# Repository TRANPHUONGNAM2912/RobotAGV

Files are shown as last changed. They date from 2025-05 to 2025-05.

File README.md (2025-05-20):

# RobotAGV

Một triển khai mô-đun và hướng đối tượng của robot AGV (Automated Guided Vehicle) sử dụng ESP32.

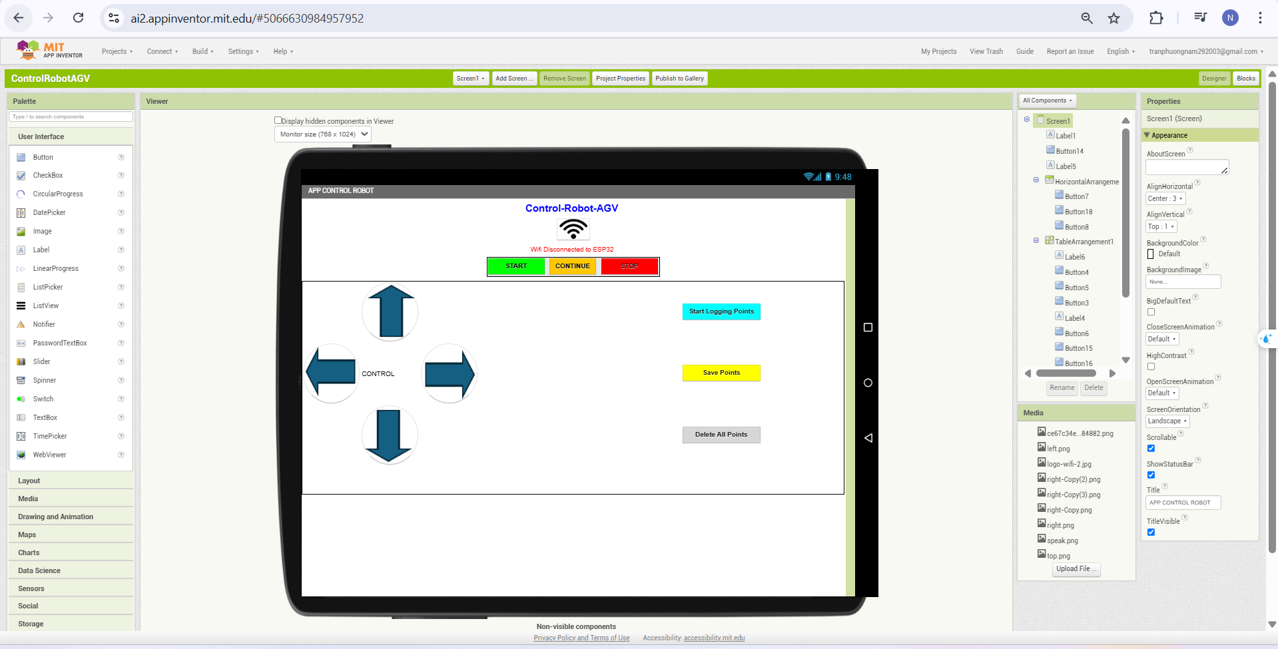
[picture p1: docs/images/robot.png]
RobotAGV


## Tổng Quan Dự Án

Repository này chứa toàn bộ mã nguồn của robot AGV dựa trên nền tảng ESP32. Dự án được cấu trúc theo nguyên tắc lập trình hướng đối tượng để dễ bảo trì và mở rộng.

### Tính Năng Chính

- **Điều hướng theo phương pháp dạy và thực hiện**: Dạy robot các đường đi thông qua ứng dụng di động mà không cần dùng dò line
- **Điều khiển PID-Backstepping**: Thuật toán điều khiển tiên tiến cho việc bám quỹ đạo chính xác
- **Điều khiển từ xa qua WiFi**: Điều khiển robot thông qua ứng dụng di động hoặc giao diện web
- **Theo dõi vị trí**: Đo lường chính xác vị trí sử dụng bộ mã hóa bánh xe
- **Kiến trúc mô-đun**: Cấu trúc mã nguồn hướng đối tượng được tổ chức tốt

## Cấu Trúc Dự Án

Mã nguồn được tổ chức thành nhiều mô-đun:

- **RobotAGV.ino**: File sketch Arduino chính khởi tạo và điều phối tất cả các thành phần
- **Config.h**: File cấu hình trung tâm với tất cả các tham số và định nghĩa chân
- **Motor.h**: Lớp điều khiển động cơ với chức năng PWM
- **Encoder.h/Encoder.cpp**: Quản lý bộ mã hóa và xử lý ngắt
- **PIDController.h**: Triển khai thuật toán điều khiển PID
- **Robot.h**: Lớp robot chính xử lý động học, theo dõi vị trí và bám quỹ đạo
- **WebServer.h**: Giao diện web để điều khiển từ xa qua WiFi

## Chi Tiết Kỹ Thuật

### Động Học Robot
- Robot sử dụng động học vi sai (differential drive)
- Theo dõi vị trí sử dụng bộ mã hóa bánh xe (x, y, theta)
- Bám quỹ đạo với hiệu chỉnh lỗi trong hệ tọa độ của robot

### Hệ Thống Điều Khiển
- Bộ điều khiển PID cho mỗi động cơ
- Thuật toán bám quỹ đạo với giảm thiểu lỗi vị trí và hướng
- Triển khai chống tích lũy (anti-windup) cho điều khiển tích phân

### Truyền Thông
- Điểm truy cập WiFi để kết nối trực tiếp
- API HTTP đơn giản cho các lệnh điều khiển
- Giao diện ứng dụng di động để dạy quỹ đạo

## Yêu Cầu Phần Cứng

- Board phát triển ESP32
- Hai động cơ DC với bộ mã hóa (234.3 xung/vòng)
- Driver động cơ H-bridge
- Màn hình LCD I2C (16x2)
- Nút nhấn để điều khiển vật lý
- Nguồn điện

## Thiết Kế PCB

Thư mục `pcb` chứa các file thiết kế PCB Altium cho phần cứng điện tử của robot. PCB tích hợp:
- Vi điều khiển ESP32
- Mạch điều khiển động cơ
- Giao diện bộ mã hóa
- Quản lý nguồn điện
- Kết nối I/O

## Ứng Dụng Di Động

Thư mục `app` chứa ứng dụng di động được thiết kế với MIT App Inventor cho phép:
- Dạy robot các đường đi mới
- Điều khiển từ xa chuyển động của robot
- Lưu trữ và quản lý nhiều quỹ đạo
- Giám sát trạng thái robot

## Hướng Dẫn Sử Dụng

### Thiết Lập
1. Tải mã nguồn lên board ESP32 với các kết nối phần cứng cần thiết
2. Bật nguồn robot
3. Kết nối với điểm truy cập WiFi (SSID: ESP32-AP, Mật khẩu: 123456789)

### Điều Khiển Từ Xa
Điều khiển robot bằng cách gửi yêu cầu HTTP đến:
- `/T`: Di chuyển tiến
- `/B`: Di chuyển lùi
- `/L`: Rẽ trái
- `/R`: Rẽ phải
- `/0`: Dừng lại
- `/1`: Bắt đầu bám quỹ đạo
- `/2`: Dừng bám quỹ đạo
- `/3`: Bắt đầu ghi quỹ đạo
- `/4`: Dừng ghi quỹ đạo
- `/5`: Xóa quỹ đạo đã ghi
- `/6`: Tiếp tục bám quỹ đạo

### Điều Khiển Vật Lý
- **Nút Start**: Bắt đầu bám quỹ đạo
- **Nút Stop**: Dừng khẩn cấp

## Chi Tiết Triển Khai

### Hệ Tọa Độ
- X: Vị trí tiến/lùi tính bằng mét
- Y: Vị trí trái/phải tính bằng mét
- Theta: Hướng tính bằng radian

### Bám Quỹ Đạo
Robot có thể ghi lại quỹ đạo khi bạn điều khiển thủ công, sau đó thực hiện lại quỹ đạo đó bằng thuật toán điều khiển giảm thiểu lỗi vị trí và hướng.

### Tính Năng Chính
1. **Dạy qua Ứng dụng Di động**: Robot có thể được dạy các đường đi thông qua ứng dụng di động mà không cần dùng đường dò line dán dưới sàn.
2. **Thuật toán PID-Backstepping**: Sử dụng điều khiển tiên tiến để bám quỹ đạo chính xác.
3. **Tự động Hiệu chỉnh Đường đi**: Nếu bị đẩy ra khỏi quỹ đạo, robot tự động quay lại đúng đường đã lập trình.
4. **Lưu trữ Vị trí**: Lưu dữ liệu vị trí để hoạt động nhất quán.
5. **Phát hiện Vật cản**: Tự động dừng lại khi phát hiện vật cản.

## Cài Đặt

1. Clone repository này
2. Mở file `src/RobotAGV.ino` trong Arduino IDE
3. Cài đặt các thư viện cần thiết:
   - WiFi
   - WebServer
   - MatrixMath
   - Wire
   - LiquidCrystal_I2C
4. Kết nối board ESP32
5. Tải sketch lên board

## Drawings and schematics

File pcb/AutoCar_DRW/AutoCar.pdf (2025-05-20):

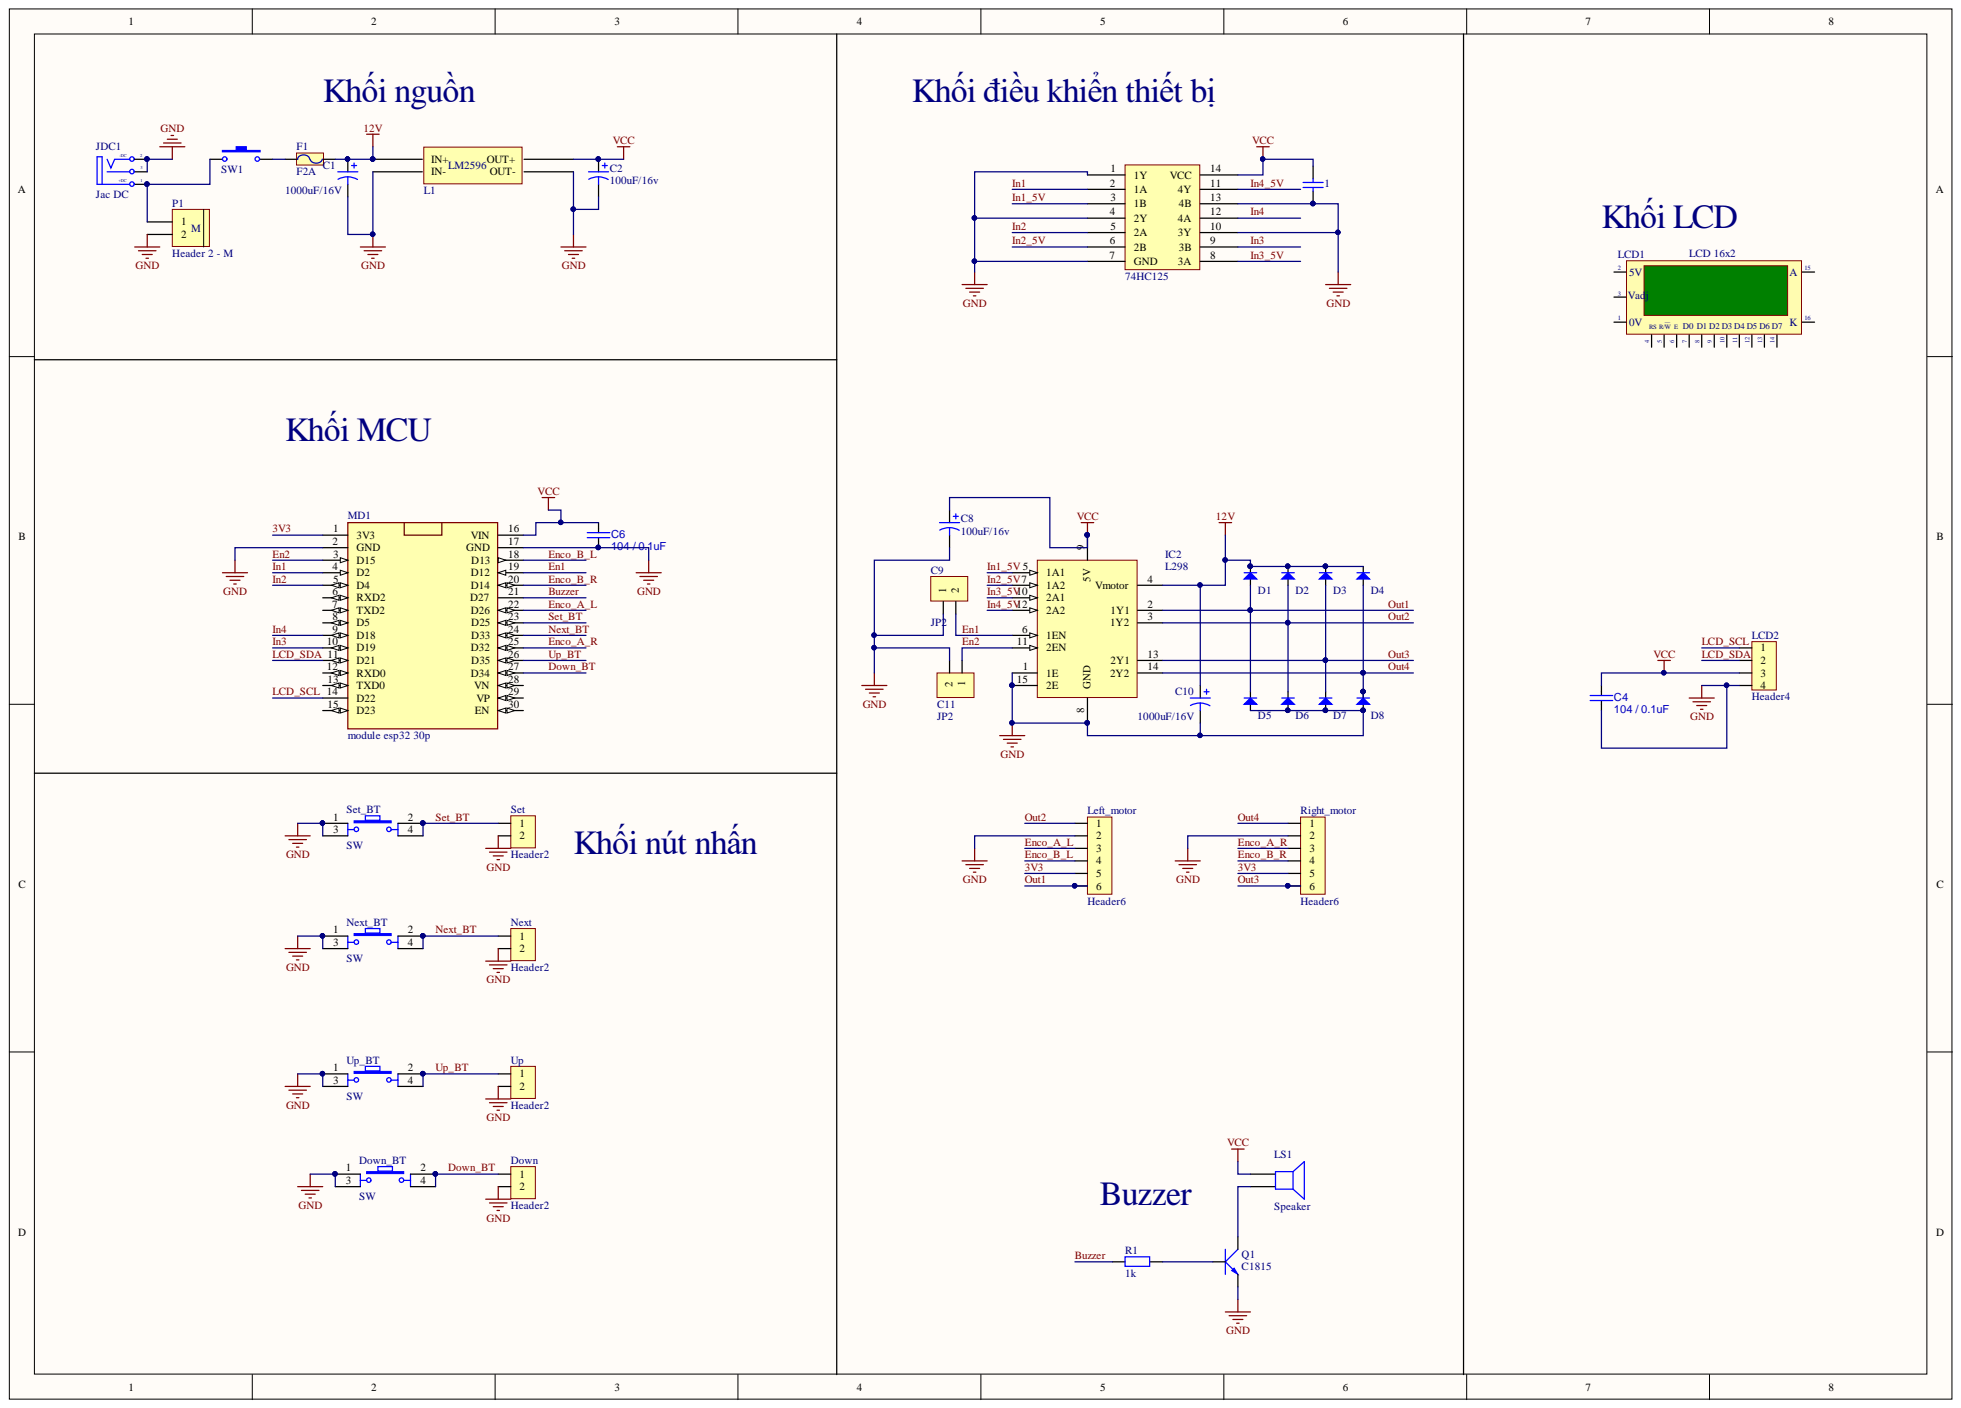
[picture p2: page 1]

Khối điều khiển thiết bị

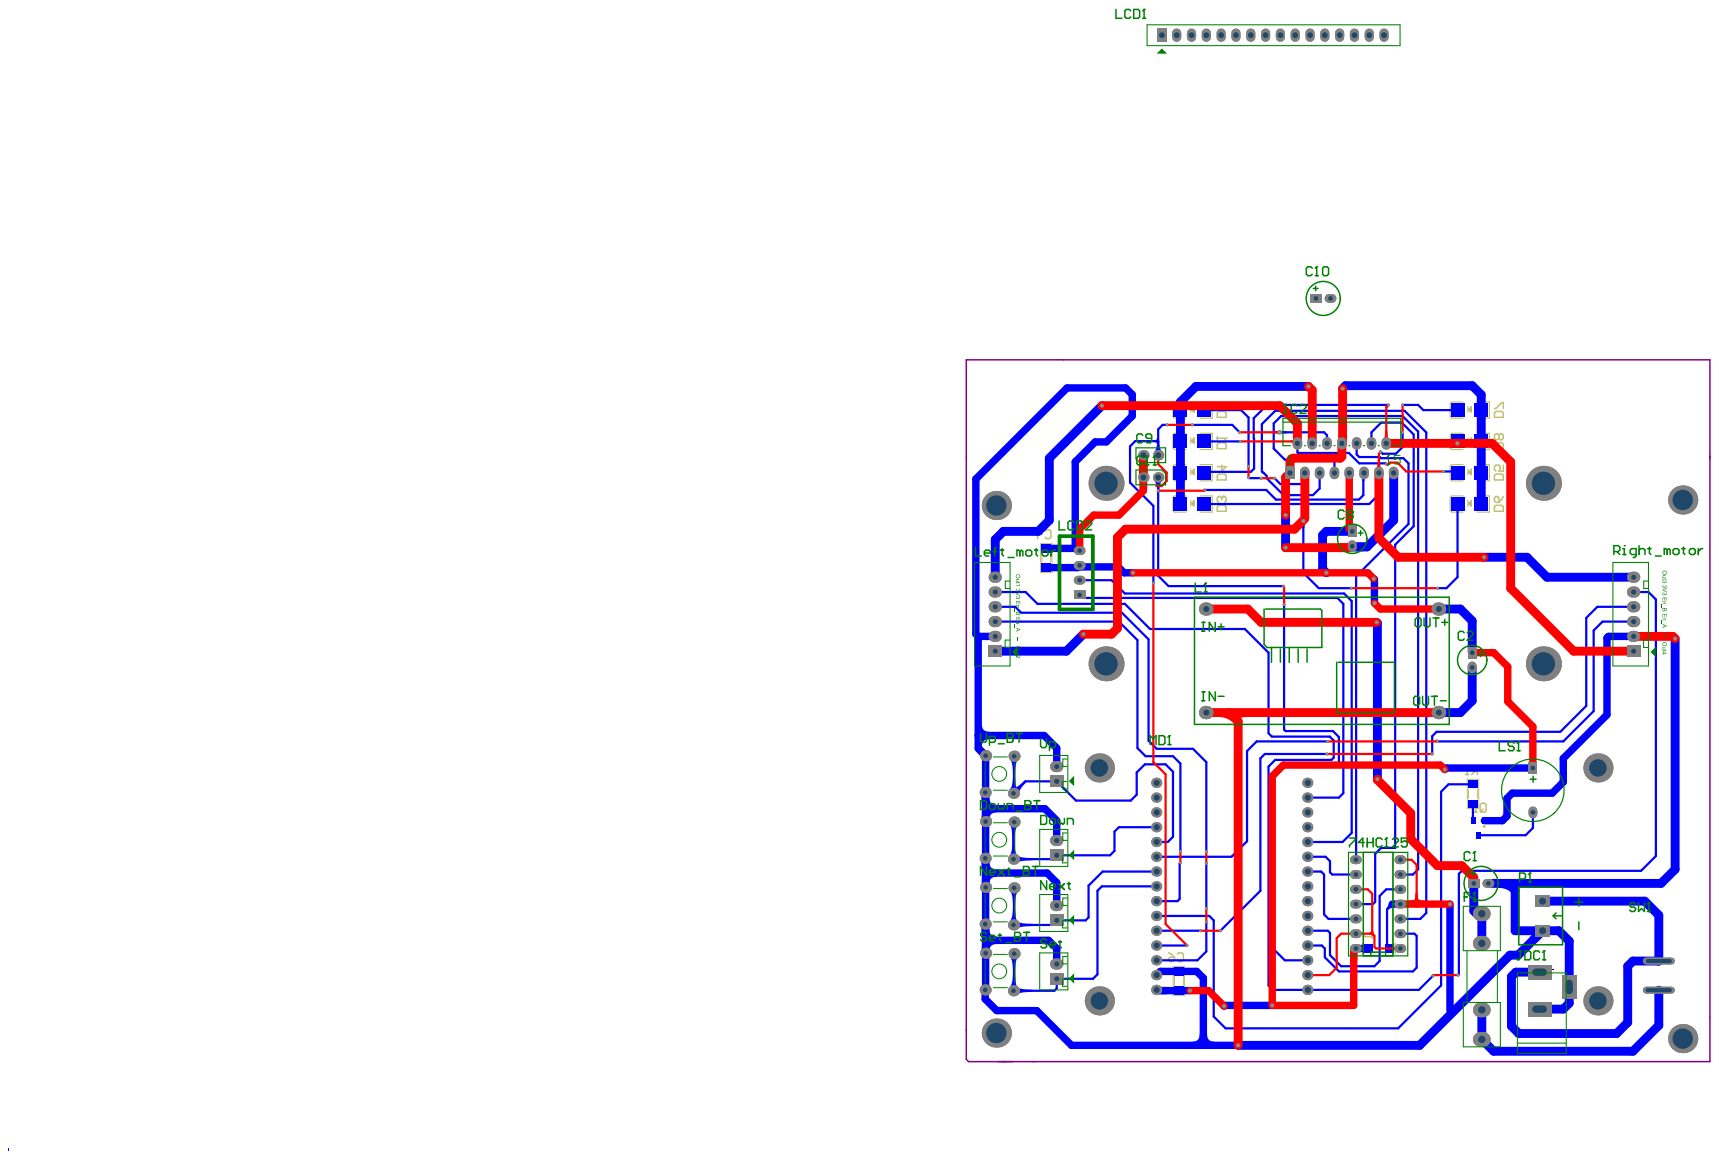
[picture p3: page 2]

Comment | Description | Designator | Footprint | LibRef | Quantity
Capacitor Ceramic | Capacitor | 1 | C1206 | CapSMD | 1
74HC02 DIP14 | Cắm | 74HC125 | dip14 | 74HC02 DIP | 1
1000uF/16V | Polarized Capacitor (Axial) | C1, C10 | C8mm | Cap Pol 12mm | 2
100uF/16v | Polarized Capacitor (Axial) | C2, C8 | C5mm | Cap Pol 5mm | 2
approved sub OK | Capacitor SMD Cer 1.8nF 10% 50V X7R 0805 | C4, C6 | SMD Capacistor 1206 | CAP C_0805 | 2
JP2 | WR-PHD 2.54 mm Angled Socket Header | C9, C11 | JP2-CLOSED | JP2 | 2
Diode SMD | Default Diode | D1, D2, D3, D4, D5, D6, D7, D8 | DIO-SMD-106 | Diode SMD | 8
Header2 | Header IDC, 2 x 1 Pin Vertical 2.54mm Pitch (Non-Boxed, Male) | Down, Next, Set, Up | Header2 | Header2 | 4
SW | Switch button 4 pin | Down_BT, Next_BT, Set_BT, Up_BT | SW4 | SW4 | 4
F2A | Fuse | F1 | Fuse | Fuse | 1
L298 | Dual Full-H Driver | IC2 | DIP15SL2 | L298 | 1
Jac DC | Jac DC input | JDC1 | DC-IN | DCIN | 1
BUCK_LM2596 | | L1 | BUCK_LM2596 | BUCK_LM2596 | 1
LCD 16x2 | | LCD1 | LCD16X2N | LCD | 1
Header4 | Header IDC, 4 x 1 Pin Vertical 2.54mm Pitch (Non-Boxed, Male) | LCD2 | XH2.54M-4 | Header4 | 1
Header6 | Header IDC, 6 x 1 Pin Vertical 2.54mm Pitch (Non-Boxed, Male) | Left_motor, Right_motor | Header6 | Header6 | 2
Speaker | Loudspeaker | LS1 | SPEAKER | Speaker | 1
module esp32 30p | | MD1 | module esp32 30 pin | module esp32 30p | 1
Header 2 - M | Header, 2-Pin, Medium | P1 | Medium - Header 2 | Header 2 - M | 1
C1815 | NPN 600mW, ECB | Q1 | SOT23B | C1815 | 1
1k | Resistor SMD 0805 | R1 | RES-SMD-1206 | R0805 | 1
KCD01-11_SWITCH | Nut Nhan 2 Chan SMD 3x6x2. SW1 | | KCD01-11 | KCD01-11_SWITCH | 1

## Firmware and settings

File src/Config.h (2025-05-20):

#ifndef CONFIG_H
#define CONFIG_H

// WiFi configuration
#define WIFI_SSID "ESP32-AP"
#define WIFI_PASSWORD "123456789"

// Robot physical parameters
#define WHEEL_DISTANCE 0.18 // Distance between wheels in meters
#define WHEEL_RADIUS 0.0325 // Wheel radius in meters (0.065/2)
#define ENCODER_TICKS_PER_REV 234.3 // Encoder ticks per revolution

// PID Controller parameters
#define PID_KP 0.02
#define PID_KI 0.00015
#define PID_KD 0.01
#define PID_MAX_OUTPUT 12.0
#define PID_MIN_OUTPUT 0.0

// Motor pins
#define MOTOR1_PIN1 2
#define MOTOR1_PIN2 4
#define MOTOR1_ENABLE 12
#define MOTOR2_PIN1 19
#define MOTOR2_PIN2 18
#define MOTOR2_ENABLE 15

// Encoder pins
#define ENCODER1_A 26
#define ENCODER1_B 13
#define ENCODER2_A 32
#define ENCODER2_B 14

// Button pins
#define BUTTON_START 25
#define BUTTON_STOP 33

// PWM configuration
#define PWM_FREQUENCY 30000
#define PWM_RESOLUTION 8
#define PWM_CHANNEL_1 0
#define PWM_CHANNEL_2 1

// LCD configuration
#define LCD_ADDRESS 0x27
#define LCD_COLUMNS 16
#define LCD_ROWS 2

// Timer configuration
#define TIMER_INTERVAL_US 150000 // 150ms

// Trajectory parameters
#define MAX_TRAJECTORY_POINTS 1000
#define DEFAULT_LINEAR_VELOCITY 0.15
#define DEFAULT_ANGULAR_VELOCITY 0.4

// Web server port
#define SERVER_PORT 80

#endif // CONFIG_H 

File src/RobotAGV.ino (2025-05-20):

#include "Config.h"
#include "Motor.h"
#include "Encoder.h"
#include "PIDController.h"
#include "Robot.h"
#include "WebServer.h"
#include <Wire.h>

// Global objects
Robot* robot = nullptr;
WebServerController* webServer = nullptr;

// Timer interrupt
hw_timer_t* timer = nullptr;
volatile unsigned long timerCount = 0;

void IRAM_ATTR onTimer() {
    timerCount++;
}

// Button interrupt handler
void IRAM_ATTR stopButtonHandler() {
    if (robot) {
        robot->stop();
    }
}

void setup() {
    // Initialize serial communication
    Serial.begin(115200);
    Serial.println("Initializing RobotAGV...");
    
    // Initialize I2C for LCD
    Wire.begin();
    
    // Create robot instance
    robot = new Robot();
    
    // Create web server instance
    webServer = new WebServerController(robot);
    
    // Initialize encoders
    encoder1 = new Encoder(ENCODER1_A, ENCODER1_B);
    encoder2 = new Encoder(ENCODER2_A, ENCODER2_B);
    
    // Set up button interrupts
    pinMode(BUTTON_START, INPUT_PULLUP);
    pinMode(BUTTON_STOP, INPUT_PULLUP);
    attachInterrupt(digitalPinToInterrupt(BUTTON_STOP), stopButtonHandler, FALLING);
    
    // Set up encoder interrupts
    attachInterrupt(digitalPinToInterrupt(ENCODER1_A), encoder1ISR, RISING);
    attachInterrupt(digitalPinToInterrupt(ENCODER2_A), encoder2ISR, RISING);
    
    // Set up timer interrupt
    timer = timerBegin(0, 80, true);
    timerAttachInterrupt(timer, &onTimer, true);
    timerAlarmWrite(timer, TIMER_INTERVAL_US, true);
    timerAlarmEnable(timer);
    
    // Initialize robot and web server
    robot->init();
    webServer->init();
    
    Serial.println("RobotAGV initialization complete");
}

void loop() {
    // Handle web server requests
    webServer->handleClient();
    
    // Check start button
    static bool prevStartButtonState = HIGH;
    bool currentStartButtonState = digitalRead(BUTTON_START);
    if (currentStartButtonState == LOW && prevStartButtonState == HIGH) {
        robot->start();
    }
    prevStartButtonState = currentStartButtonState;
    
    // Update robot state
    static unsigned long lastUpdateTime = 0;
    static unsigned long lastDisplayTime = 0;
    static unsigned long prevTimerCount = 0;
    
    // Update robot position at regular intervals
    if (timerCount != prevTimerCount) {
        robot->update();
        prevTimerCount = timerCount;
        
        // Display status every second
        unsigned long currentTime = millis();
        if (currentTime - lastDisplayTime >= 1000) {
            robot->displayStatus();
            lastDisplayTime = currentTime;
        }
    }
} 

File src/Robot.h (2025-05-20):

#ifndef ROBOT_H
#define ROBOT_H

#include "Config.h"
#include "Motor.h"
#include "Encoder.h"
#include "PIDController.h"
#include <Arduino.h>
#include <LiquidCrystal_I2C.h>

class Robot {
private:
    // Components
    Motor* leftMotor;
    Motor* rightMotor;
    PIDController* leftPID;
    PIDController* rightPID;
    LiquidCrystal_I2C* lcd;
    
    // Robot state
    float x;
    float y;
    float theta;
    float linearVelocity;
    float angularVelocity;
    
    // Trajectory data
    float trajectoryX[MAX_TRAJECTORY_POINTS];
    float trajectoryY[MAX_TRAJECTORY_POINTS];
    float trajectoryTheta[MAX_TRAJECTORY_POINTS];
    int trajectoryIndex;
    int currentTrajectoryPoint;
    
    // Control flags
    bool isRunning;
    bool isRecording;
    
    // Previous values for calculations
    float prevX;
    float prevY;
    float prevTheta;
    unsigned long prevTime;
    
public:
    Robot() : 
        x(0), y(0), theta(0), linearVelocity(0), angularVelocity(0),
        trajectoryIndex(0), currentTrajectoryPoint(0),
        isRunning(false), isRecording(false),
        prevX(0), prevY(0), prevTheta(0), prevTime(0) {
        
        // Initialize components
        leftMotor = new Motor(MOTOR1_PIN1, MOTOR1_PIN2, MOTOR1_ENABLE, PWM_CHANNEL_1);
        rightMotor = new Motor(MOTOR2_PIN1, MOTOR2_PIN2, MOTOR2_ENABLE, PWM_CHANNEL_2);
        leftPID = new PIDController();
        rightPID = new PIDController();
        lcd = new LiquidCrystal_I2C(LCD_ADDRESS, LCD_COLUMNS, LCD_ROWS);
        
        // Initialize LCD
        lcd->init();
        lcd->backlight();
    }
    
    ~Robot() {
        delete leftMotor;
        delete rightMotor;
        delete leftPID;
        delete rightPID;
        delete lcd;
    }
    
    void init() {
        // Additional initialization if needed
        reset();
    }
    
    void reset() {
        x = 0;
        y = 0;
        theta = 0;
        linearVelocity = 0;
        angularVelocity = 0;
        trajectoryIndex = 0;
        currentTrajectoryPoint = 0;
        isRunning = false;
        isRecording = false;
        
        leftPID->reset();
        rightPID->reset();
        
        // Reset encoders
        encoder1->reset();
        encoder2->reset();
        
        // Clear trajectory data
        clearTrajectory();
    }
    
    void clearTrajectory() {
        for (int i = 0; i < MAX_TRAJECTORY_POINTS; i++) {
            trajectoryX[i] = 0;
            trajectoryY[i] = 0;
            trajectoryTheta[i] = 0;
        }
        trajectoryIndex = 0;
        currentTrajectoryPoint = 0;
    }
    
    void updatePosition() {
        unsigned long currentTime = millis();
        float deltaTime = (currentTime - prevTime) / 1000.0;
        
        if (prevTime == 0 || deltaTime <= 0) {
            prevTime = currentTime;
            return;
        }
        
        // Get wheel velocities from encoders
        float leftWheelVelocity = encoder1->getDistance() / deltaTime;
        float rightWheelVelocity = encoder2->getDistance() / deltaTime;
        
        // Reset encoder counts for next calculation
        encoder1->reset();
        encoder2->reset();
        
        // Calculate robot velocities
        linearVelocity = (rightWheelVelocity + leftWheelVelocity) / 2.0;
        angularVelocity = (leftWheelVelocity - rightWheelVelocity) / WHEEL_DISTANCE;
        
        // Update position and orientation
        theta += angularVelocity * deltaTime;
        x += linearVelocity * cos(theta + (angularVelocity * deltaTime / 2.0)) * deltaTime;
        y += linearVelocity * sin(theta + (angularVelocity * deltaTime / 2.0)) * deltaTime;
        
        prevTime = currentTime;
        
        // Save trajectory point if recording
        if (isRecording && (theta != prevTheta || x != prevX || y != prevY)) {
            saveTrajectoryPoint();
        }
        
        // Update previous values
        prevX = x;
        prevY = y;
        prevTheta = theta;
    }
    
    void saveTrajectoryPoint() {
        if (trajectoryIndex < MAX_TRAJECTORY_POINTS) {
            trajectoryX[trajectoryIndex] = x;
            trajectoryY[trajectoryIndex] = y;
            trajectoryTheta[trajectoryIndex] = theta;
            
            Serial.print("Index ");
            Serial.print(trajectoryIndex);
            Serial.print(": theta = ");
            Serial.print(theta);
            Serial.print(", x = ");
            Serial.print(x);
            Serial.print(", y = ");
            Serial.println(y);
            
            trajectoryIndex++;
        }
    }
    
    void followTrajectory() {
        if (!isRunning || trajectoryIndex == 0 || currentTrajectoryPoint >= trajectoryIndex) {
            stop();
            return;
        }
        
        // Get target point from trajectory
        float targetX = trajectoryX[currentTrajectoryPoint];
        float targetY = trajectoryY[currentTrajectoryPoint];
        float targetTheta = trajectoryTheta[currentTrajectoryPoint];
        
        // Calculate errors in robot's coordinate frame
        float errorX = targetX - x;
        float errorY = targetY - y;
        float errorTheta = targetTheta - theta;
        
        // Transform errors to robot frame
        float errorXRobot = cos(theta) * errorX + sin(theta) * errorY;
        float errorYRobot = -sin(theta) * errorX + cos(theta) * errorY;
        
        // Calculate control inputs
        float linearVelocityCommand = 2.0 * errorXRobot;
        float angularVelocityCommand = 2.0 * errorYRobot + 2.0 * errorTheta;
        
        // Calculate wheel velocities
        float rightWheelVelocity = (2 * linearVelocityCommand + (WHEEL_DISTANCE * angularVelocityCommand)) / 2.0;
        float leftWheelVelocity = 2 * linearVelocityCommand - rightWheelVelocity;
        
        // Apply wheel velocities through PID controllers
        float leftRPM = abs((leftWheelVelocity / (2 * PI * WHEEL_RADIUS)) * 60);
        float rightRPM = abs((rightWheelVelocity / (2 * PI * WHEEL_RADIUS)) * 60);
        
        // Get current wheel velocities
        float currentLeftRPM = (encoder1->getCount() / ENCODER_TICKS_PER_REV) * 60;
        float currentRightRPM = (encoder2->getCount() / ENCODER_TICKS_PER_REV) * 60;
        
        // Compute PID outputs
        float leftOutput = leftPID->compute(leftRPM, currentLeftRPM);
        float rightOutput = rightPID->compute(rightRPM, currentRightRPM);
        
        // Set motor speeds with direction
        leftMotor->setSpeed(leftWheelVelocity > 0 ? leftOutput / PID_MAX_OUTPUT : -leftOutput / PID_MAX_OUTPUT);
        rightMotor->setSpeed(rightWheelVelocity > 0 ? rightOutput / PID_MAX_OUTPUT : -rightOutput / PID_MAX_OUTPUT);
        
        // Debug output
        Serial.println(targetX);
        Serial.println(targetY);
        Serial.println(targetTheta);
        Serial.println(x);
        Serial.println(y);
        Serial.println(theta);
        Serial.println(currentTrajectoryPoint);
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
